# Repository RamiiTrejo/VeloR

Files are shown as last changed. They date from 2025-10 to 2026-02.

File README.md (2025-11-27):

[README.md](https://github.com/user-attachments/files/22640474/README.md)
# Velocista "VeloR" - Robot Seguidor de Línea

## Descripción

El velocista "VeloR" es un robot seguidor de línea diseñado para competir en desafíos de velocidad y precisión. Este repositorio posee el diseño de hardware, firmware, 3D relacionados con VeloR. Aquí encontrarás toda la información necesaria para comprender el robot seguidor de línea VeloR.

## Características principales

- **Seguimiento de línea**: VeloR utilizará la regleta QTR8A para seguir líneas con precisión y rapidez.

- **Velocidad**: Utiliza unos motores de 3600RPM para alcanzar altas velocidades y realizar maniobras bruscas en conjunto a sus ruedas que le ayudan a tener mejor agarre en la pista.

## Contenidos
- **Firmware**: En esta carpeta encontrarás el código fuente del firmware utilizado en VeloR. El firmware está escrito en lenguaje C++ y se basa en la plataforma de desarrollo ESP32. Incluye los algoritmos de control, la lógica de seguimiento de línea y la comunicación con los sensores y actuadores del robot.
- **Hardware**: Aquí se encuentran los diseños y esquemas del hardware electrónico utilizado en VeloR. Estos archivos incluyen los esquemas de conexión y los diagramas de circuitos.

## 🎉Objetivo

 El objetivo propuesto de este robot seguidor de línea **VeloR** es ir a competir en las ligas de "Carreras" en la Liga Nacional de Robotica
 
## ⚒ Componentes principales
- Microcontolador ESP32 embebido
- 2-Controlador de motores TA6586
- Batería 3S 450mAh
- DISPLAY OLED 64X128
- Motorreductor ProFast 12v 3600RPM
- RUEDAS DE SILICONA MICRO JS2114 
- Regleta de QTR8A 

## IMAGENES PCB
<div align="center">
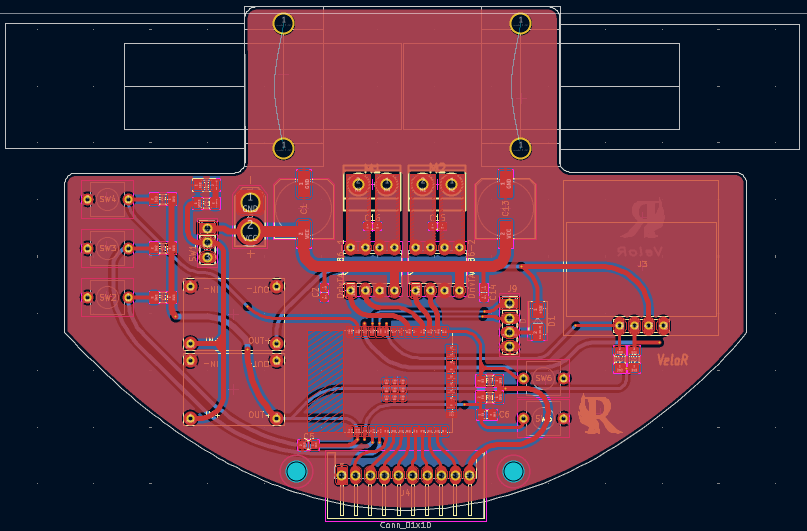
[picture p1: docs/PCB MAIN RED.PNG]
PCB MAIN RED

 <br>
 <strong>FRONT VIEW</strong>
</div> 

<div align="center">
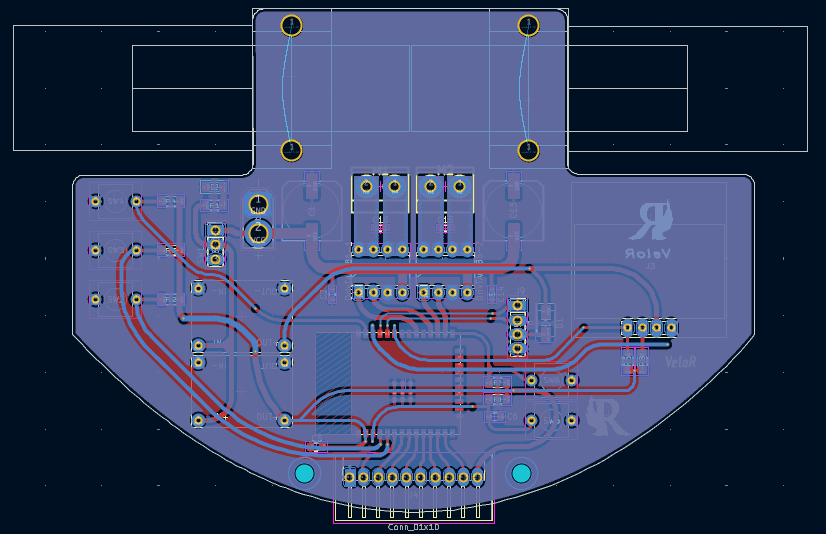
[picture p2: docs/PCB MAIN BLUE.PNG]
PCB MAIN BLUE

 <br>
 <strong>BACK VIEW</strong>
</div> 

<div align="center">
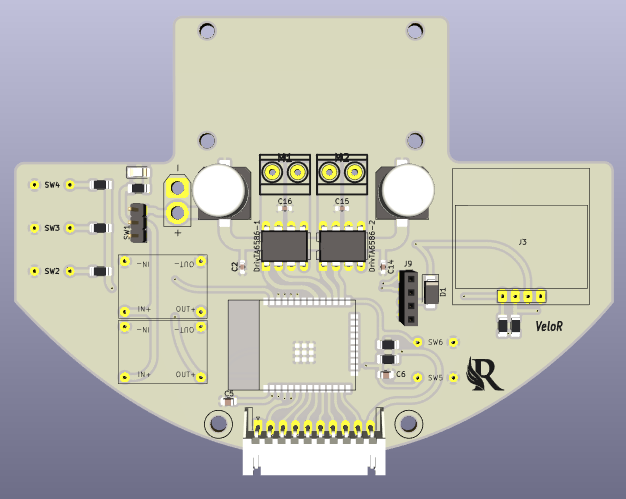
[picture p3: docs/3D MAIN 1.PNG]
3D MAIN 1

 <br>
 <strong>3D PCB</strong>
</div> 

<div align="center">
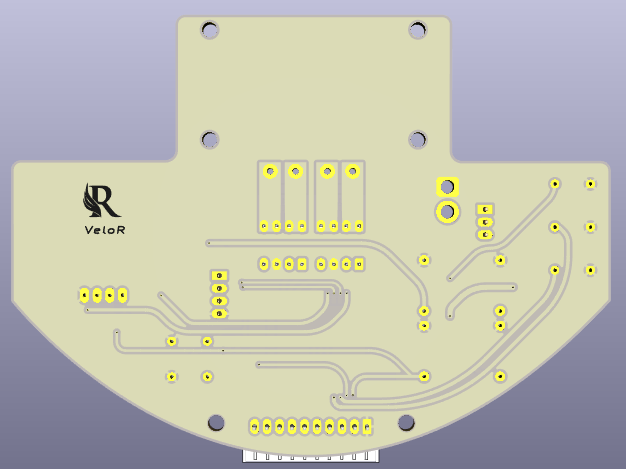
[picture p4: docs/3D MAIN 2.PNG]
3D MAIN 1

</div>

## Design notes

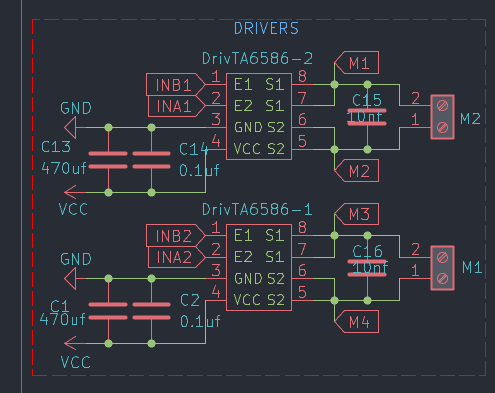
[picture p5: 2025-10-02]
docs/DRIVERS.PNG

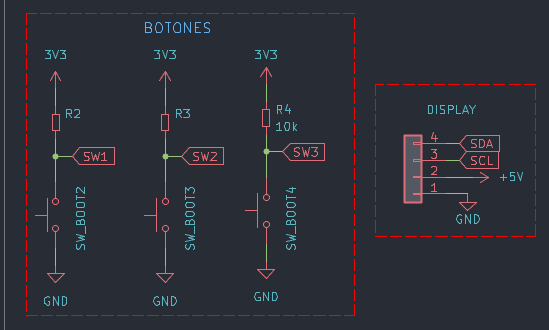
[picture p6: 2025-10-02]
docs/SCH-DISPLAY-BUTTONS.PNG

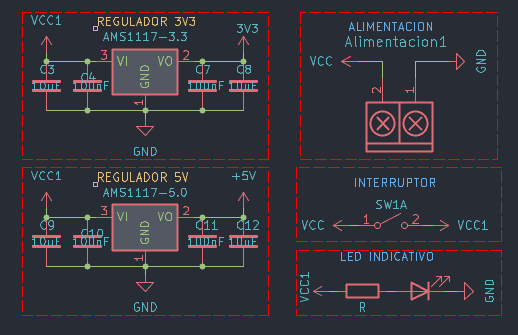
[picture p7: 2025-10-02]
docs/SCH-ALIMENTACION.PNG

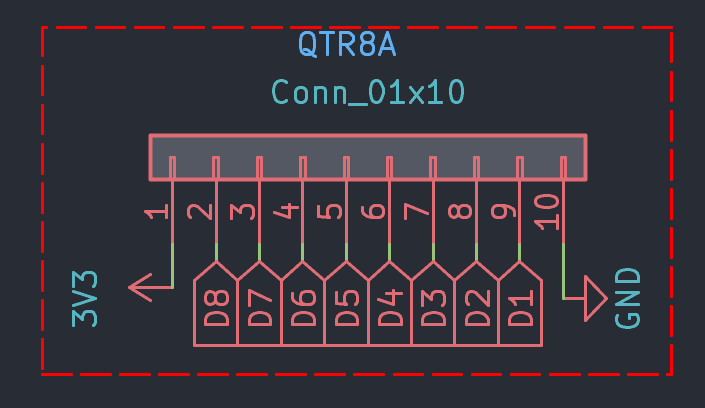
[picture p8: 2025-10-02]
docs/QTR8A.PNG

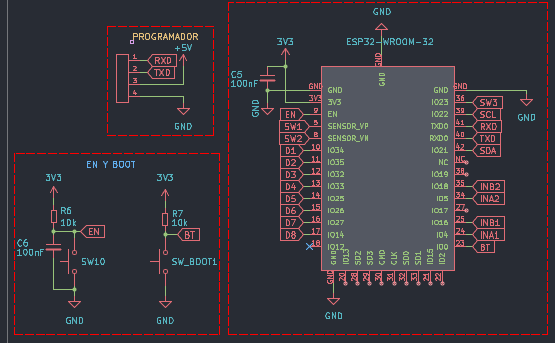
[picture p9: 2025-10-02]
docs/ESP32-EN-BOOT-PRGRAMMER.PNG

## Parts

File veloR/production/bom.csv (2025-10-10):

Designator | Footprint | Quantity | Value | LCSC Part #
ALIMENTACION1 | AMASS_XT30U-M_1x02_P5.0mm_Vertical | 1 | TB_1X2
C1, C13 | C_Elec_10x10.2 | 2 | 470uf
C10, C11, C4, C5, C6, C7 | 0805 | 6 | 100nF
C12, C3, C8, C9 | 0805 | 4 | 10uF
C14, C2 | 0603 | 2 | 0.1uf
C15, C16 | 0603 | 2 | 10nf
D1 | D_SMA | 1 | D
D2 | 1206 | 1 | LED
DRIVTA6586-1, DRIVTA6586-2 | DIP-8_W7.62mm | 2 | ~
J3 | 128x64OLED | 1 | DISPLAY
J4 | JST_XH_S10B-XH-A-1_1x10_P2.50mm_Horizontal | 1 | Conn_01x10
J9 | PinSocket_1x04_P2.54mm_Vertical | 1 | Programador
M1 | BORNERA2_AZUL | 1 | M1
M2 | BORNERA2_AZUL | 1 | M2
M3, M4 | motor 3600rpm | 2 | Motor_DC
R1 | 1206 | 1 | R
R2, R3, R4, R5, R6, R7, R8 | 1206 | 7 | 10k
SW1 | PinHeader_1x03_P2.54mm_Vertical | 1 | SW_DPST_x2
SW10, SW_BOOT1 | Pulsador_SMD_2_ALTO | 2 | SW_Push
SW_BOOT2, SW_BOOT3, SW_BOOT4 | Button | 3 | SW_Push
U3 | SOT-223-3_TabPin2 | 1 | AMS1117-3.3
U6 | ESP32-WROOM-32E | 1 | ESP32-WROOM-32
U7 | SOT-223-3_TabPin2 | 1 | AMS1117-5.0

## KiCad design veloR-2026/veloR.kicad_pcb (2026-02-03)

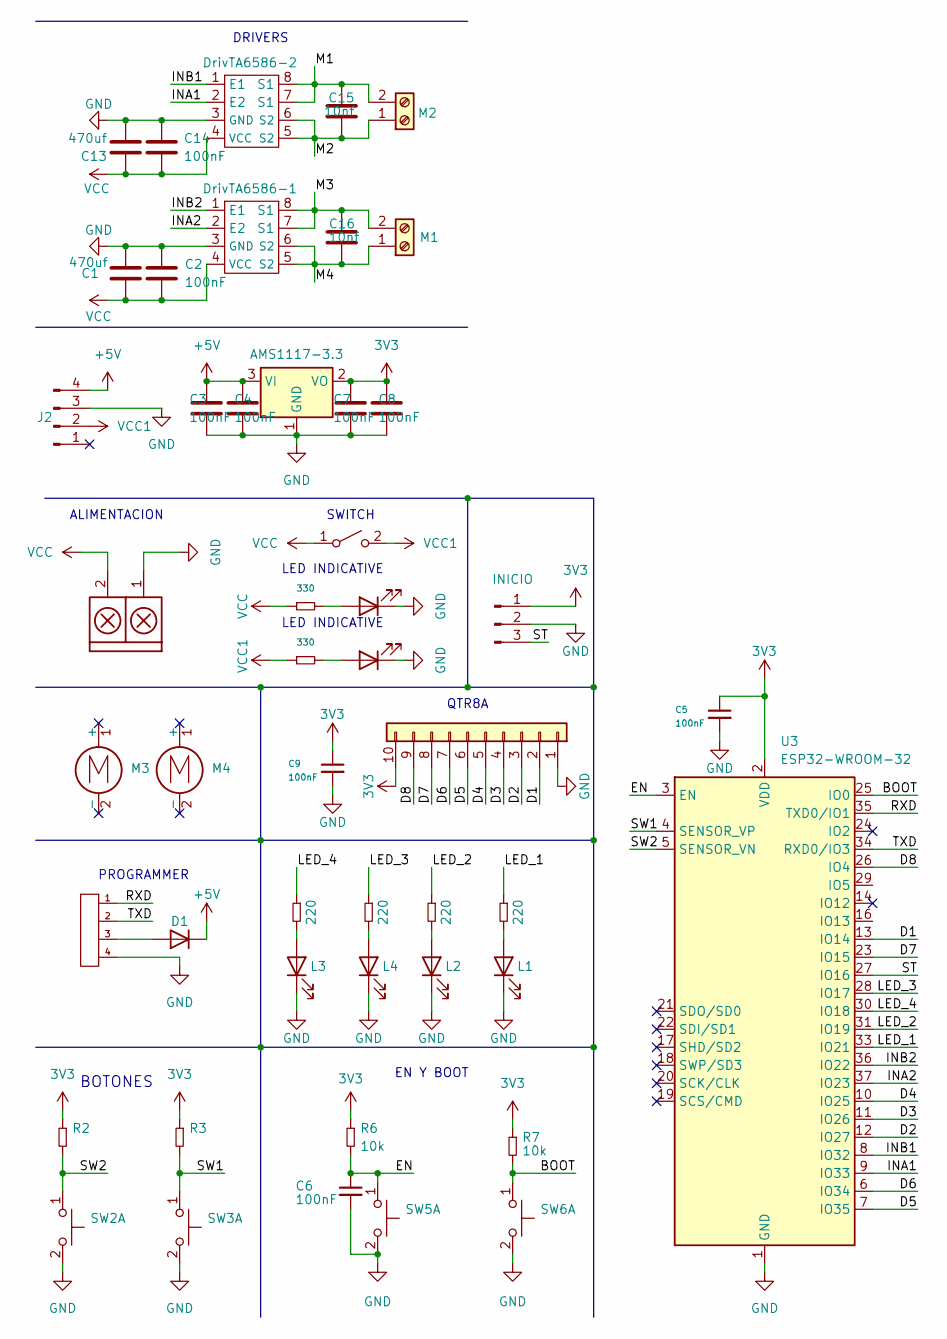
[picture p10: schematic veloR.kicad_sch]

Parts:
Alimentacion1: TB_1X2; AMASS_XT30U-M_1x02_P5.0mm_Vertical
C1, C13: 470uf; CP_EIA-7343-30_AVX-N_HandSolder
C2, C3, C4, C5, C6, C7, C8, C9, C14: 100nF; C_0805_2012Metric_Pad1.18x1.45mm_HandSolder
C15, C16: 10nf; C_0805_2012Metric_Pad1.18x1.45mm_HandSolder
D1: D; D_SMA
D2, D3: LED; LED_0805_2012Metric_Pad1.15x1.40mm_HandSolder
DrivTA6586-1, DrivTA6586-2: DIP-8_W7.62mm
J2: Conn_01x04_Pin; Step_Down_Mini
J3: INICIO; PinHeader_1x03_P2.54mm_Vertical
J4: Conn_01x10; JST_XH_S10B-XH-A_1x10_P2.50mm_Horizontal
J9: Programador; PinHeader_1x04_P2.54mm_Horizontal
L1, L2, L3, L4: LED; LED_0805_2012Metric_Pad1.15x1.40mm_HandSolder
M1: M1; JST_XH_B2B-XH-A_1x02_P2.50mm_Vertical
M2: M2; JST_XH_B2B-XH-A_1x02_P2.50mm_Vertical
M3, M4: Motor_DC; motor pololu
R2, R3, R6, R7: 10k; R_0805_2012Metric_Pad1.20x1.40mm_HandSolder
R13, R14, R15, R16: 220; R_0805_2012Metric_Pad1.20x1.40mm_HandSolder
R17, R18: 330; R_0805_2012Metric_Pad1.20x1.40mm_HandSolder
SW1: SW_DPST_x2; PinHeader_1x03_P2.54mm_Vertical
SW2, SW3, SW5, SW6: SW_Push_Dual_x2; SW SMD 3.5X6X5
U1: AMS1117-3.3; SOT-223-3_TabPin2
U3: ESP32-WROOM-32

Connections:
3V3: C5.1, C7.1, C8.1, C9.1, J3.1, J4.10, R2.1, R3.1, R6.1, R7.1, U1.2 (VO), U3.2 (VDD)
+5V: C3.1, C4.1, D1.1 (K), J2.4, U1.3 (VI)
/BOOT: R7.2, SW6.1 (C), U3.25 (IO0)
/D1: J4.2, U3.13 (IO14)
/D2: J4.3, U3.12 (IO27)
/D3: J4.4, U3.11 (IO26)
/D4: J4.5, U3.10 (IO25)
/D5: J4.6, U3.7 (IO35)
/D6: J4.7, U3.6 (IO34)
/D7: J4.8, U3.23 (IO15)
/D8: J4.9, U3.26 (IO4)
/EN: C6.1, R6.2, SW5.1 (C), U3.3 (EN)
/INA1: DrivTA6586-2.2 (E2), U3.9 (IO33)
/INA2: DrivTA6586-1.2 (E2), U3.37 (IO23)
/INB1: DrivTA6586-2.1 (E1), U3.8 (IO32)
/INB2: DrivTA6586-1.1 (E1), U3.36 (IO22)
/LED_1: R13.1, U3.33 (IO21)
/LED_2: R14.1, U3.31 (IO19)
/LED_3: R16.1, U3.28 (IO17)
/LED_4: R15.1, U3.30 (IO18)
/M1: C15.1, DrivTA6586-2.7 (S1), DrivTA6586-2.8 (S1), M2.2
/M2: C15.2, DrivTA6586-2.5 (S2), DrivTA6586-2.6 (S2), M2.1
/M3: C16.1, DrivTA6586-1.7 (S1), DrivTA6586-1.8 (S1), M1.2
/M4: C16.2, DrivTA6586-1.5 (S2), DrivTA6586-1.6 (S2), M1.1
/RXD: J9.1, U3.35 (TXD0/IO1)
/ST: J3.3, U3.27 (IO16)
/SW1: R3.2, SW3.1 (C), U3.4 (SENSOR_VP)
/SW2: R2.2, SW2.1 (C), U3.5 (SENSOR_VN)
/TXD: J9.2, U3.34 (RXD0/IO3)
GND: Alimentacion1.1, C1.2, C2.1, C3.2, C4.2, C5.2, C6.2, C7.2, C8.2, C9.2, C13.2, C14.1, D2.1 (K), D3.1 (K), DrivTA6586-1.3 (GND), DrivTA6586-2.3 (GND), J2.3, J3.2, J4.1, J9.4, L1.1 (K), L2.1 (K), L3.1 (K), L4.1 (K), SW2.2 (D), SW3.2 (D), SW5.2 (D), SW6.2 (D), U1.1 (GND), U3.1 (GND), U3.15 (GND), U3.38 (GND), U3.39 (GND)
unnamed: D1.2 (A), J9.3
unnamed: D2.2 (A), R17.2
unnamed: D3.2 (A), R18.2
unnamed: L1.2 (A), R13.2
unnamed: L2.2 (A), R14.2
unnamed: L3.2 (A), R15.2
unnamed: L4.2 (A), R16.2
VCC: Alimentacion1.2, C1.1, C2.2, C13.1, C14.2, DrivTA6586-1.4 (VCC), DrivTA6586-2.4 (VCC), R18.1, SW1.1 (A)
VCC1: J2.2, R17.1, SW1.2 (B)

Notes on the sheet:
EN Y BOOT
BOTONES
LED INDICATIVE
SWITCH
ALIMENTACION
DRIVERS
QTR8A
PROGRAMMER

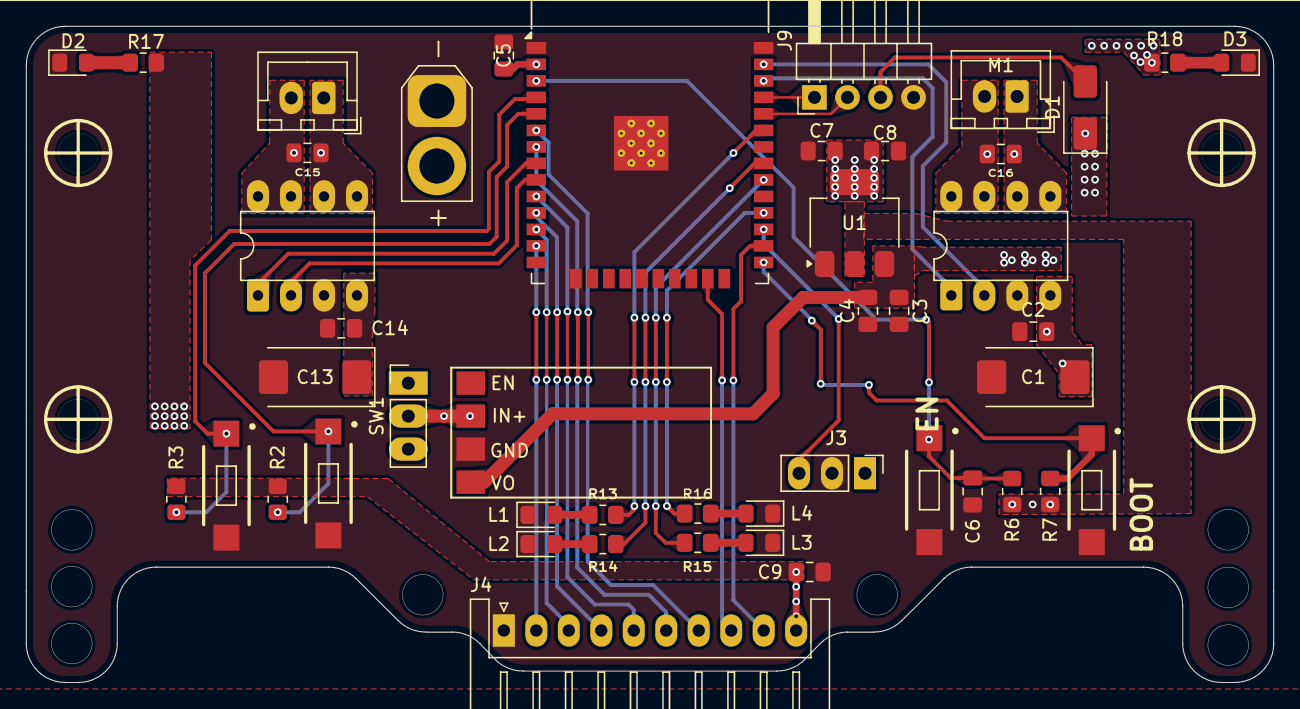
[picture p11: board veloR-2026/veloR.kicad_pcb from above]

Board: 2 copper layers, 96.0 x 50.5 mm, 48 parts (0 on the bottom side), 39 nets.

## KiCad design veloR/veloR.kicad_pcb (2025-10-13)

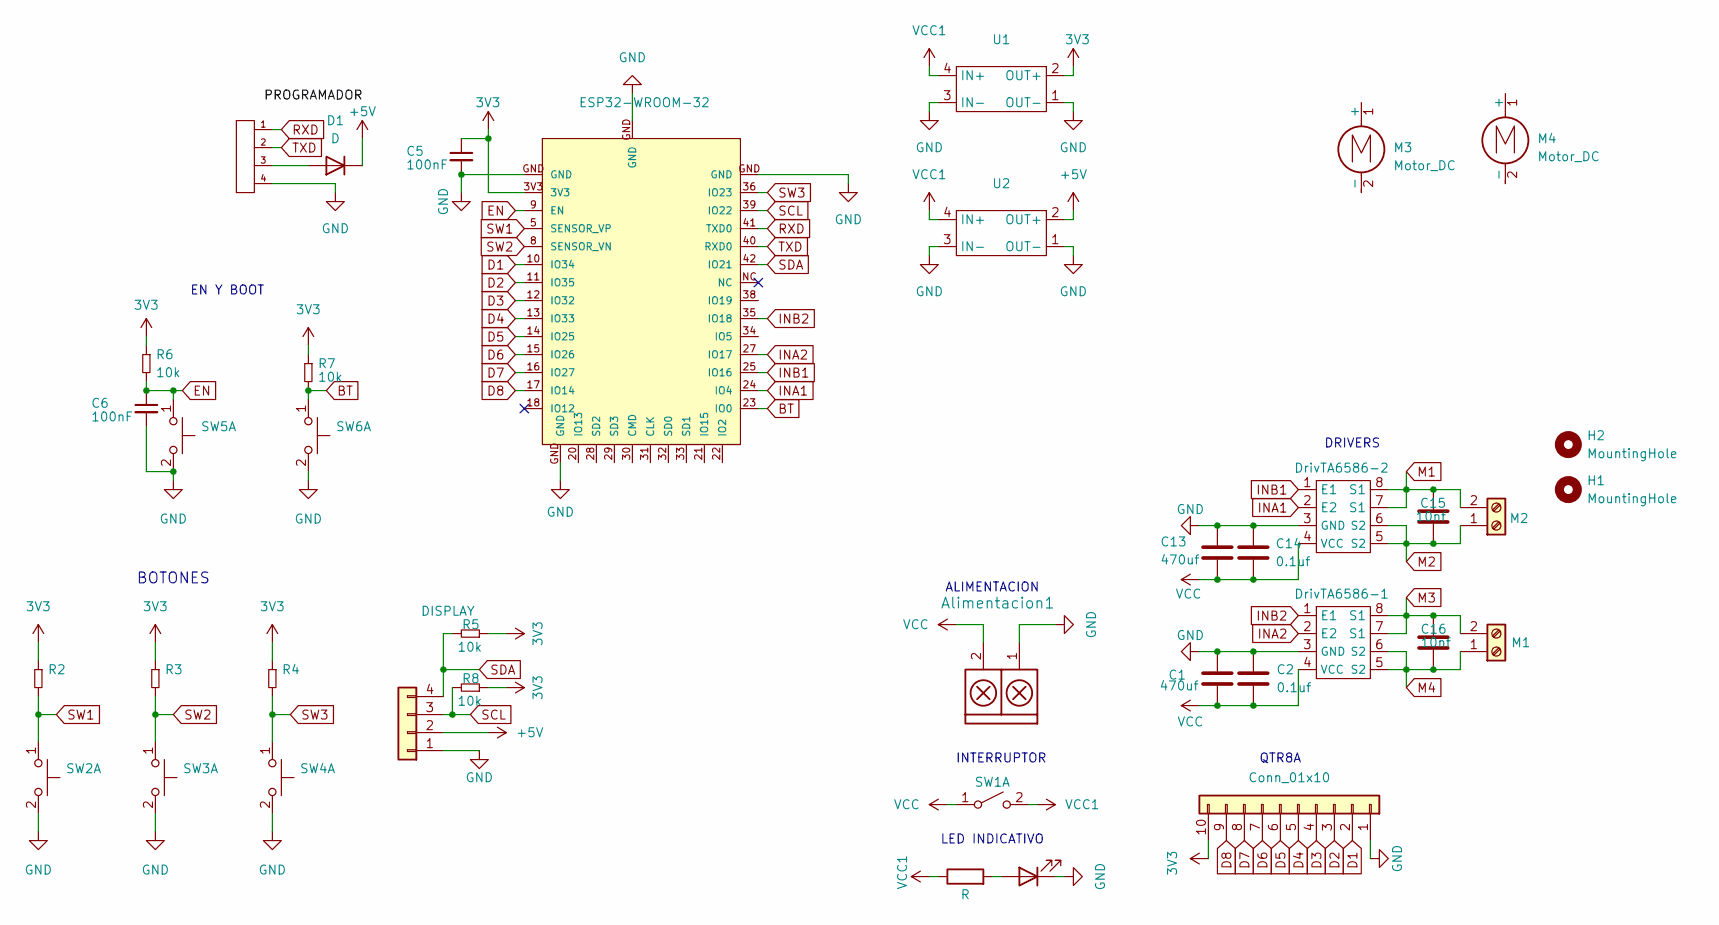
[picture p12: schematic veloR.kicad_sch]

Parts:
Alimentacion1: TB_1X2; AMASS_XT30U-M_1x02_P5.0mm_Vertical
C1, C13: 470uf; C_Elec_10x10.2
C2, C14: 0.1uf; C_0603_1608Metric_Pad1.08x0.95mm_HandSolder
C5, C6: 100nF; C_0805_2012Metric_Pad1.18x1.45mm_HandSolder
C15, C16: 10nf; C_0603_1608Metric_Pad1.08x0.95mm_HandSolder
D1: D; D_SMA
D2: LED; LED_1206_3216Metric_Pad1.42x1.75mm_HandSolder
DrivTA6586-1, DrivTA6586-2: DIP-8_W7.62mm
H1, H2: MountingHole; MountingHole_3.2mm_M3_DIN965
J3: DISPLAY; 128x64OLED
J4: Conn_01x10; JST_XH_S10B-XH-A-1_1x10_P2.50mm_Horizontal
J9: Programador; PinSocket_1x04_P2.54mm_Vertical
M1: M1; BORNERA2_AZUL
M2: M2; BORNERA2_AZUL
M3, M4: Motor_DC; motor 3600rpm
R1: R; R_1206_3216Metric_Pad1.30x1.75mm_HandSolder
R2, R3, R4, R5, R6, R7, R8: 10k; R_1206_3216Metric_Pad1.30x1.75mm_HandSolder
SW1: SW_DPST_x2; PinHeader_1x03_P2.54mm_Vertical
SW2, SW3, SW4, SW5, SW6: SW_Push_Dual_x2; SW 6MM 2 PIN
U1, U2: STEP DOWN MINI 360
U6: ESP32-WROOM-32; ESP32-WROOM-32E

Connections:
3V3: C5.1, J4.10, R2.1, R3.1, R4.1, R5.1, R6.1, R7.1, R8.1, U1.2 (OUT+), U6.3V3
+5V: D1.1 (K), J3.2, U2.2 (OUT+)
BT: R7.2, SW6.1 (C), U6.23 (IO0)
D1: J4.2, U6.10 (IO34)
D2: J4.3, U6.11 (IO35)
D3: J4.4, U6.12 (IO32)
D4: J4.5, U6.13 (IO33)
D5: J4.6, U6.14 (IO25)
D6: J4.7, U6.15 (IO26)
D7: J4.8, U6.16 (IO27)
D8: J4.9, U6.17 (IO14)
EN: C6.1, R6.2, SW5.1 (C), U6.9 (EN)
GND: Alimentacion1.1, C1.1, C2.1, C5.2, C6.2, C13.1, C14.1, D2.1 (K), DrivTA6586-1.3 (GND), DrivTA6586-2.3 (GND), J3.1, J4.1, J9.4, SW2.2 (D), SW3.2 (D), SW4.2 (D), SW5.2 (D), SW6.2 (D), U1.1 (OUT-), U1.3 (IN-), U2.1 (OUT-), U2.3 (IN-), U6.GND
INA1: DrivTA6586-2.2 (E2), U6.24 (IO4)
INA2: DrivTA6586-1.2 (E2), U6.27 (IO17)
INB1: DrivTA6586-2.1 (E1), U6.25 (IO16)
INB2: DrivTA6586-1.1 (E1), U6.35 (IO18)
M1: C15.1, DrivTA6586-2.7 (S1), DrivTA6586-2.8 (S1), M2.2
M2: C15.2, DrivTA6586-2.5 (S2), DrivTA6586-2.6 (S2), M2.1
M3: C16.1, DrivTA6586-1.7 (S1), DrivTA6586-1.8 (S1), M1.2
M4: C16.2, DrivTA6586-1.5 (S2), DrivTA6586-1.6 (S2), M1.1
unnamed: D1.2 (A), J9.3
unnamed: D2.2 (A), R1.2
RXD: J9.1, U6.41 (TXD0)
SCL: J3.3, R8.2, U6.39 (IO22)
SDA: J3.4, R5.2, U6.42 (IO21)
SW1: R2.2, SW2.1 (C), U6.5 (SENSOR_VP)
SW2: R3.2, SW3.1 (C), U6.8 (SENSOR_VN)
SW3: R4.2, SW4.1 (C), U6.36 (IO23)
TXD: J9.2, U6.40 (RXD0)
VCC: Alimentacion1.2, C1.2, C2.2, C13.2, C14.2, DrivTA6586-1.4 (VCC), DrivTA6586-2.4 (VCC), SW1.1 (A)
VCC1: R1.1, SW1.2 (B), U1.4 (IN+), U2.4 (IN+)

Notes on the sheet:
EN Y BOOT
BOTONES
INTERRUPTOR
ALIMENTACION
DRIVERS
QTR8A
LED INDICATIVO

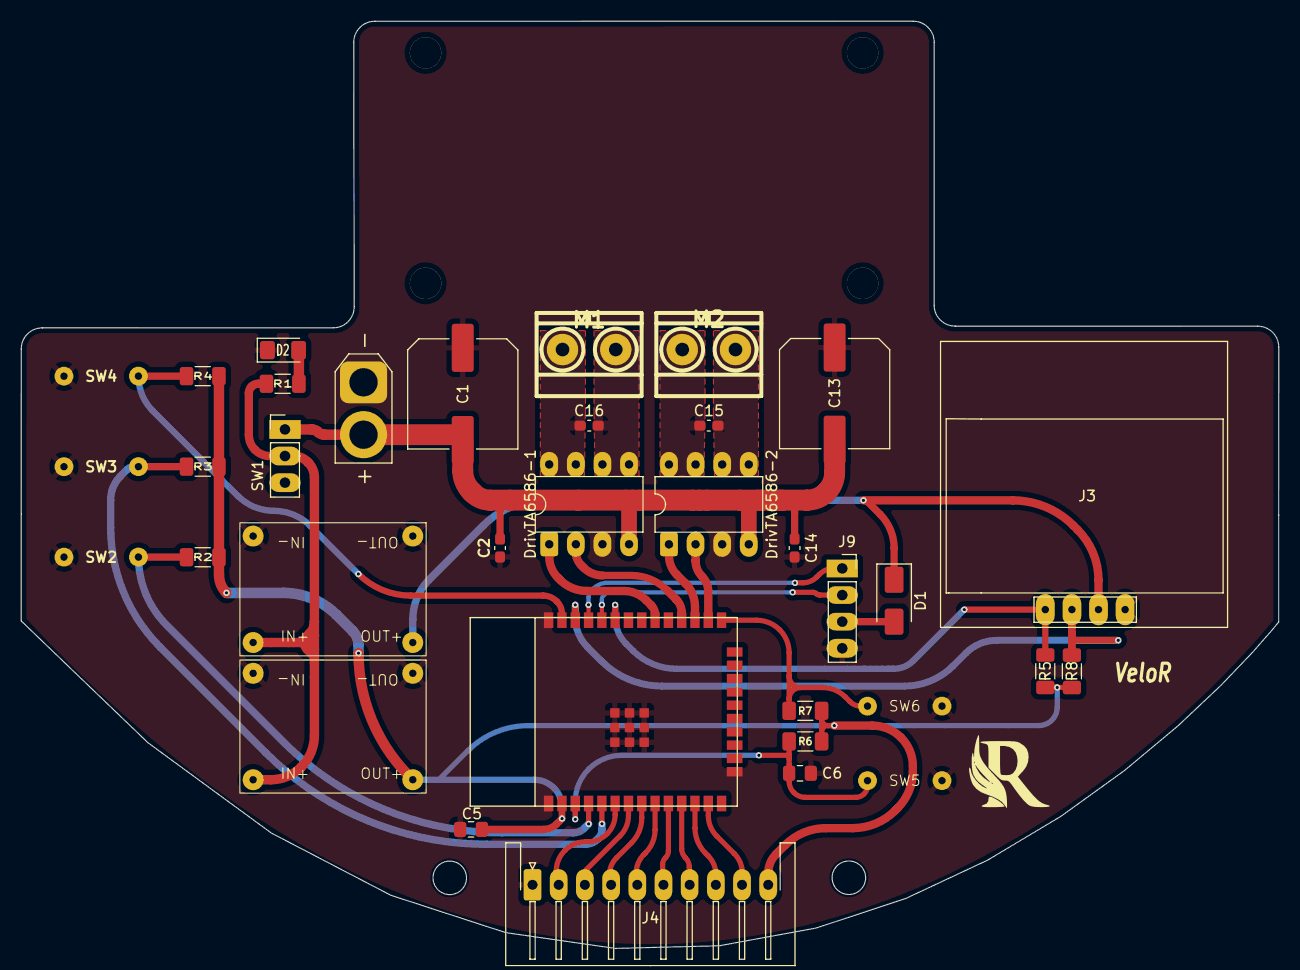
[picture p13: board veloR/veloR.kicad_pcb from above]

Board: 2 copper layers, 120.1 x 88.5 mm, 39 parts (0 on the bottom side), 32 nets.

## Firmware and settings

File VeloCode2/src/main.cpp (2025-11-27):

#include <Arduino.h>

// --- DEFINICIONES GLOBALES (ANTES DE LAS CLASES) ---
// Para que NUM_SENSORES sea conocido en la clase Robot_Velocista
#define NUM_SENSORES 8

// CLASE MOTOR

class Motor
{
private:
  int _inA;
  int _inB;

public:
  Motor(int inA, int inB) : _inA(inA), _inB(inB)
  {
    // Es mejor usar ledcAttachPin() para asociar el pin con un canal PWM en ESP32
    // Pero para simplificar y mantener la lógica original, asumiremos que
    // ledcWrite() está manejando implícitamente la configuración si los pines son PWM.
    // Sin embargo, en un entorno ESP32 real, deberías usar ledcSetup y ledcAttachPin
    pinMode(_inA, OUTPUT);
    pinMode(_inB, OUTPUT);
    // Para simplificar, asumimos que ledcWrite() es la forma correcta para mover
    // el motor con PWM en ESP32 para este ejemplo.
  }

  void mover(int velocidad)
  {
    // Limitar velocidad entre -255 y 255
    velocidad = constrain(velocidad, -255, 255);

    if (velocidad > 0)
    {
      // Adelante (Motor A en HIGH/PWM, Motor B en LOW/0)
      ledcWrite(_inA, velocidad);
      ledcWrite(_inB, 0);
    }
    else if (velocidad < 0)
    {
      // Atrás (Motor A en LOW/0, Motor B en HIGH/PWM)
      // Usamos el valor absoluto de la velocidad para el PWM
      ledcWrite(_inA, 0);
      ledcWrite(_inB, -velocidad);
    }
    else
    {
      // Detener
      ledcWrite(_inA, 0);
      ledcWrite(_inB, 0);
    }
  }

  void detener()
  {
    ledcWrite(_inA, 0);
    ledcWrite(_inB, 0);
  }
};

// CLASE ROBOT (VELOCISTA)

class Robot_Velocista
{
private:
  Motor _motorIzq;
  Motor _motorDer;
  int _velocidadBase;
  // El array de pines debe ser almacenado como un puntero o un array estático
  const int* _pinesSensores; 
  int _numSensores;

  // PID
  float _Kp; // Añadir el prefijo '_' para variables miembro
  float _Ki;
  float _Kd;

  // Integral (falta en tu código original, necesaria para Ki)
  float _integral = 0.0;

  // UMBRAL y ERRORES
  int _umbral; // Añadir el prefijo '_'
  // int _error = 0; // Se calcula en seguirLinea(), no es necesario guardarlo como miembro
  int _ultimoError = 0; // Añadir el prefijo '_'

public:
  // Constructor: Se modifican los parámetros y la lista de inicialización
  Robot_Velocista(int inA_izq, int inB_izq, int inA_der, int inB_der,
                  const int pinesSensores[], // Recibe el array como puntero
                  int numSensores,
                  int velocidadBase = 150,
                  float Kp = 0.15, float Ki = 0.0, float Kd = 0.8,
                  int umbral = 500)

      // Lista de inicialización corregida: se usan los prefijos '_'
      : _motorIzq(inA_izq, inB_izq),
        _motorDer(inA_der, inB_der),
        _velocidadBase(velocidadBase),
        _pinesSensores(pinesSensores), // Inicializa el puntero con el puntero recibido
        _numSensores(numSensores),
        _Kp(Kp), _Ki(Ki), _Kd(Kd),
        // No inicializamos _ultimoError en la lista, ya tiene valor por defecto
        _umbral(umbral)
  {
    // En el constructor: configuramos los pines como INPUT
    // Ya que _pinesSensores ahora apunta al array pinesSensores global/pasado,
    // usamos ese puntero para configurar los pines.
    for (int i = 0; i < _numSensores; i++)
    {
      // pinMode() necesita el valor del pin, que está en la posición i del array
      pinMode(_pinesSensores[i], INPUT); 
    }
    
    // La función 'setUmbral' estaba definida DENTRO del constructor, lo que es un error
    // Se ha movido fuera del constructor como un método público.
  }
  
  // --- MÉTODOS PÚBLICOS ---

  void setUmbral(int u)
  {
    _umbral = constrain(u, 0, 1023);
  }

  void setVelocidadBase(int vel)
  {
    _velocidadBase = constrain(vel, 0, 255);
  }

  // Mover con velocidades independientes
  void mover(int velIzq, int velDer)
  {
    _motorIzq.mover(velIzq);
    _motorDer.mover(velDer);
  }

  // Avanzar recto
  void avanzar()
  {
    mover(_velocidadBase, _velocidadBase);
  }

  // Girar con corrección
  void girar(int correccion)
  {
    int velIzq = _velocidadBase + correccion;
    int velDer = _velocidadBase - correccion;
    mover(velIzq, velDer);
  }

  void detener()
  {
    _motorIzq.detener();
    _motorDer.detener();
  }

  int leerLinea()
  {
    // NUM_SENSORES está definido como macro al inicio del archivo
    int valores[NUM_SENSORES];
    long suma = 0; // Usar long para evitar desbordamiento en sumas grandes
    long sumaPonderada = 0;

    // Leer sensores
    for (int i = 0; i < NUM_SENSORES; i++)
    {
      // Usamos el puntero a los pines miembro _pinesSensores
      // Leemos los pines como digitales (0 o 1). Si fueran analógicos, sería analogRead().
      valores[i] = digitalRead(_pinesSensores[i]); 
      suma += valores[i];
      sumaPonderada += (long)valores[i] * i * 1000;
    }

    // Calcular posición (-3500 a 3500 para 8 sensores, si se usa 0-7 como peso)
    if (suma == 0)
    {
      return _ultimoError; // Usar _ultimoError (variable miembro)
    }

    // Posición centrada es: (NUM_SENSORES - 1) * 1000 / 2 = 7 * 1000 / 2 = 3500
    // La posición retornada será (sumaPonderada / suma) - 3500
    int posicion = (int)(sumaPonderada / suma) - ((NUM_SENSORES - 1) * 500); 
    return posicion;
  }

  void seguirLinea()
  {
    int posicion = leerLinea();
    int error = posicion; // El error es la posición (0 = centrado)

    // Cálculo PID
    float proporcional = error;

    // Cálculo de la integral (si se usa Ki)
    _integral += error; 

    float derivativo = error - _ultimoError; // Usar _ultimoError

    // Se usa float para el cálculo y luego se convierte a int para la corrección
    int correccion = (int)((_Kp * proporcional) + (_Ki * _integral) + (_Kd * derivativo));

    int velIzq = _velocidadBase + correccion;
    int velDer = _velocidadBase - correccion;

    _motorIzq.mover(velIzq);
    _motorDer.mover(velDer);

    _ultimoError = error; // Guardar el error actual para la próxima iteración
  }

  void info()
  {
    Serial.println("=== CONFIGURACIÓN ROBOT ===");
    Serial.print("Velocidad base: ");
    Serial.println(_velocidadBase);
    Serial.print("Kp: ");
    Serial.println(_Kp); // Usar _Kp (variable miembro)
    Serial.print("Ki: ");
    Serial.println(_Ki); // Usar _Ki (variable miembro)
    Serial.print("Kd: ");
    Serial.println(_Kd); // Usar _Kd (variable miembro)
    Serial.print("Umbral: ");
    Serial.println(_umbral); // Usar _umbral (variable miembro)
    Serial.print("Numero de Sensores: ");
    Serial.println(_numSensores);
  }
};

// CONFIGURACIÓN DE PINES

#define MOTOR_IZQ_A 17
#define MOTOR_IZQ_B 18
#define MOTOR_DER_A 16
#define MOTOR_DER_B 4

// Pines del sensor QTR
const int pinesSensores[NUM_SENSORES] = {34, 35, 32, 33, 25, 26, 28, 14}; 
// NUM_SENSORES debe estar definido ANTES de su uso aquí

Robot_Velocista robot(MOTOR_IZQ_A, MOTOR_IZQ_B, MOTOR_DER_A, MOTOR_DER_B, 
                      pinesSensores, 
                      NUM_SENSORES, 
                      150);

void setup()
{
  Serial.begin(9600);
  robot.info();
  Serial.println("Robot listo. Esperando 2 segundos...");
  delay(2000);
}

void loop()
{
  robot.seguirLinea(); // 'seguirLinea' es un método de la instancia 'robot'
}

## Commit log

2025-10-03 Add files via upload
    MODIFIQUE PANTALLA, ACOMODE COSAS, ETC
    [veloR.kicad_pcb, veloR.kicad_sch]
2025-10-13 Add files via upload
    en este archivo se cambio los reguladores de tension por step down mini 360
    [veloR.kicad_pcb, veloR.kicad_sch]
